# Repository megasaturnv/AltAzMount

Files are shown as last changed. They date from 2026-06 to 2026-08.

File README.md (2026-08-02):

> [!WARNING]
> This project is currently work in progress. Not everything will work as intended

# AltAzMount
Alt Az (Pan Tilt) mount that tracks celestial objects based on Right Ascension and Declination. It can accept LX200 commands from planetarium software such as Stellarium via serial or it calculate the position of certain objects directly on the ESP32 and track them across the sky (currently only the sun and moon)

video of Alt Az Mount design 2

## ESP32 Code
Contains the code for running on the ESP32 controller. it uses an MKS DLC32 as the main control board and has an OLED with rotary encoder as an interface.

## Python Code
Scripts that can control the mount to create an image based on the data received or simulate visualisations of Alt-Az movement.

## 3D Print Design 1 - Original Design (Old)

This design is now deprecated and it is recommended to use design 2 in this repository. The worm gears gave good precision but the large size introduced a lot of flex in the design

M3 screws and nut of various sizes required to build this mount. 4x M4 screws and nuts required for VESA mount.

## 3D Print Design 2 - Remix of isaac879
### This is remixed from isaac879's design here:
<https://github.com/isaac879/Pan-Tilt-Mount>  
<https://www.thingiverse.com/thing:4547074>  

### List of changes:
* Added 18650s
* Added OLED + rotary encoder board, 18650 USB C charge controller, balance board and battery gauge
* Added quick mount for tripods (varies slightly per tripod)
* Added stepper motor sun shields
* Added RTC module mount
* Added 40mm fan mount
* Added limit switch for altitude (tilt) axis
* Added more mounting options such as quick connect for a tripod and a ground spike
* Extended altitude (tilt) axis by 25mm upwards
* Modified camera mount to use VESA with 75mm spacing
* Modified design to use MKS DLC32 circuit board
* Square M3 nuts modified to take M3 hex nuts

M3 screws and nut of various sizes required to build this mount. 4x M4 screws and nuts required for VESA mount.

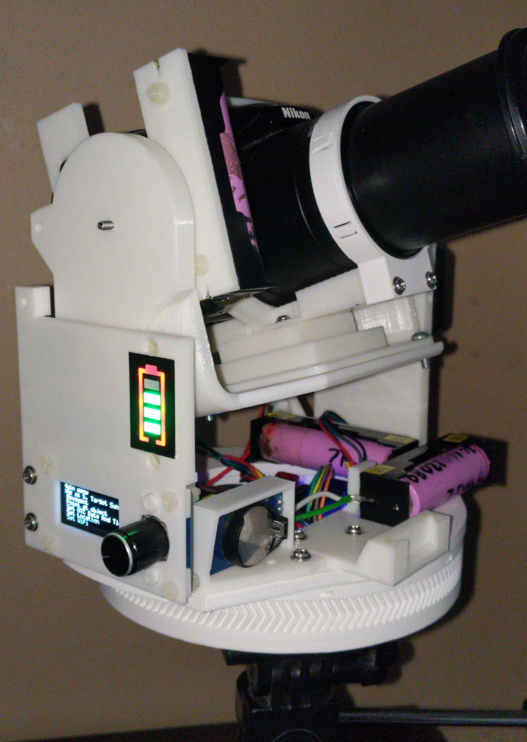
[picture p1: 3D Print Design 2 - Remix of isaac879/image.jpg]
image of Alt Az Mount design 2


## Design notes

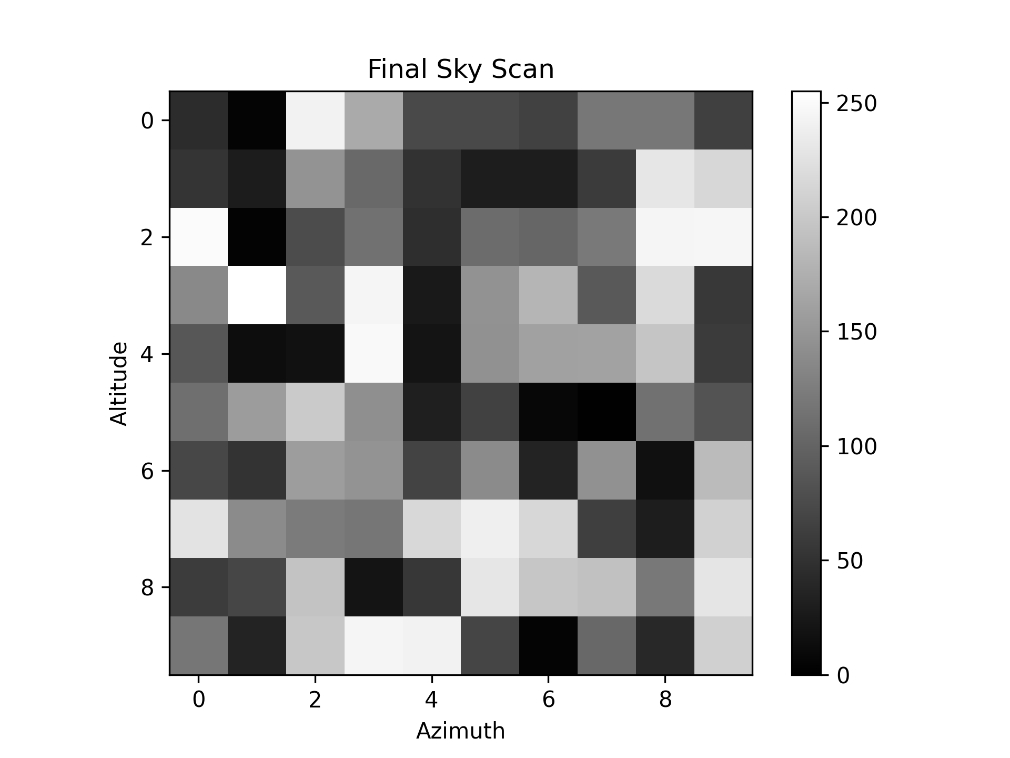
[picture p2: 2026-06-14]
Python Code/Scanning - Light Sensor/scan_2026-05-21_00-07-52 Random Data.png

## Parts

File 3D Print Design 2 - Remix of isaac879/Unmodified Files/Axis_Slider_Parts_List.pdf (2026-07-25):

isaac879

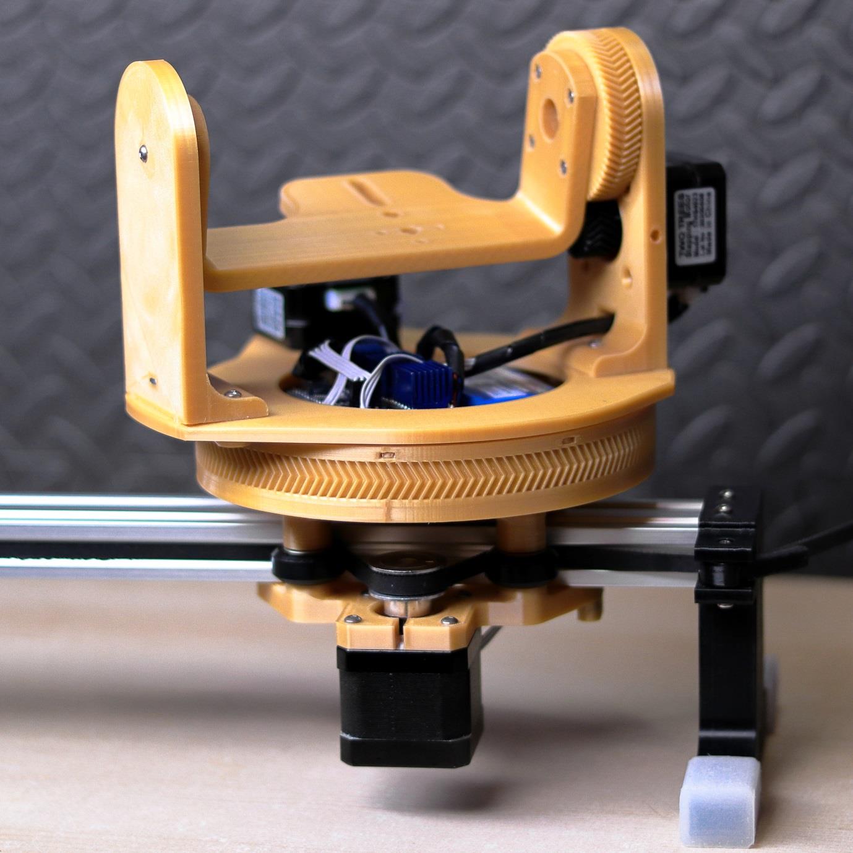
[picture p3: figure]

Linear Slider | Page 1 of 3

# 3-Axis Slider Parts List

3-Axis Slider Parts | Quantity
Nema 17 42 x 42 x 40mm Stepper Motor | 2
Nema 17 42 x 42 x 23mm Stepper Motor | 1
TMC2208 Stepper Motor Driver | 3
Arduino Nano | 1
JDY-31 Bluetooth Module (Alternatively HC-05, HC-06 or JDY-30) | 1
A3144 Hall Effect Sensor | 3
6.4mm diameter x 1.7mm Neodymium Magnets | 2
3.2mm diameter x 1.7mm Neodymium Magnets | 4
2N3904 NPN Transistor | 1
330Ω Resistor | 1
470Ω Resistor | 1
15kΩ Resistor | 1
22kΩ Resistor | 1
33kΩ Resistor | 2
100µF Electrolytic Capacitor | 3
2 Pin Plug-In Screw Terminal Block Connector 5.08mm Pitch (for power) | 1
6 Pin Female Header Connector 2.54mm (for Bluetooth module) | 1
15 Pin Female Header Connector 2.54mm (for Arduino Nano) | 2
15 Pin Male Header Connector 2.54mm (for Arduino Nano) | 2
8 Pin Female Header Connector 2.54mm (for Stepper drivers) | 6
8 Pin Male Header Connector 2.54mm (for Stepper drivers) | 6
XH2.54 4 Pin Terminal Socket Header (for Stepper motors) | 3
XH2.54 4 Pin Terminal Socket Plug (for Stepper motors) | 3
XH2.54 3 Pin Terminal Socket Header (for Hall Effect) | 3
XH2.54 3 Pin Terminal Socket Plug (for Hall Effect) | 3
XH2.54 2 Pin Terminal Socket Header (for camera shutter trigger) | 1
XH2.54 2 Pin Terminal Socket Plug (for camera shutter trigger) | 1
2.5mm 3 pole Jack Male (for camera trigger) | 1
11.1V 3S LiPo Battery or 12V DC Power Source and connector to screw terminal | 1
Pan Tilt Mount PCB | 1
Solder Wire
Cyanoacrylate or Hot Glue (for magnets and Hall Effect sensor) Wire (for Stepper motors, Hall sensors, Bluetooth module)
M3 Hexagonal Nyloc Nut | 16
M3 Square Nut | 10
M3 Button Head Hex Bolt 40mm | 4
M3 Button Head Hex Bolt 20mm | 3
M3 Button Head Hex Bolt 16mm | 10
M3 Button Head Hex Bolt 12mm | 14
M3 Button Head Hex Bolt 8mm | 5
M3 Button Head Hex Bolt 6mm | 5
M3 Button Head Hex Bolt 3.5mm | 1
Camera Mounting Bolt | 1
M3 T-Nut for Aluminium Extrusion Profile | 4

Screw 2mm Outer Thread Diameter, 6mm Long | 3
2GT Timing Belt | 1
2GT Timing Pulley 36 Teeth | 1
V-Slot 2040 Aluminium Extrusion | 1
F623ZZ Flange Bushing Ball Bearings 3 x 10 x 4mm | 6
V-Slot Pulley Wheels with Bearings (24 x 16 x 10.2mm) | 4
3D Printed Parts
127 x 146.05 x 12.7mm INA CSXU050-2RS Bearing Or 3D printable bearing parts 1-3 and 28 x 6mm balls (BB pellets) | 1
21 Tooth Herringbone Gear | 1
64 Tooth Herringbone Gear | 1
17 Tooth Herringbone Gear | 1
144 Tooth Herringbone Gear Base Mount | 1
Tilt U-Mount | 1
Idle Side Bearing Mount | 1
Gear Side Bearing Mount | 1
Idle Side Support | 1
Gear Side Support | 1
Pan Mount | 1
Pan Mount Bearing Clamp | 1
Base Mount Bearing Clip Ring | 1
2040 hall clamp | 1
2040 slider carriage top | 1
2040 slider carriage bottom | 1
2040 belt clamp side 1 | 1
2040 belt clamp side 2 | 1
2040 support leg (Optional)
Belt clamp lever | 2
3mm to 5mm wheel bearing spacer centred | 4
5mm to 8mm shaft spacer (for timing pulley if it has a 8mm bore) | 1

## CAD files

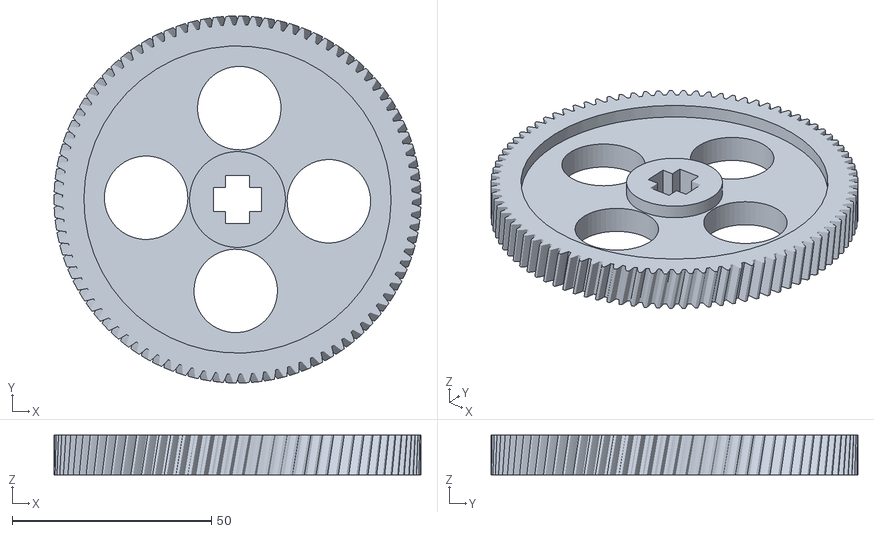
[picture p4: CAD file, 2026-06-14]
3D Prints - OpenSCAD/STLs/Main_WormGearDesign Nema 17_spur.stl
92.0 x 92.0 x 10.0

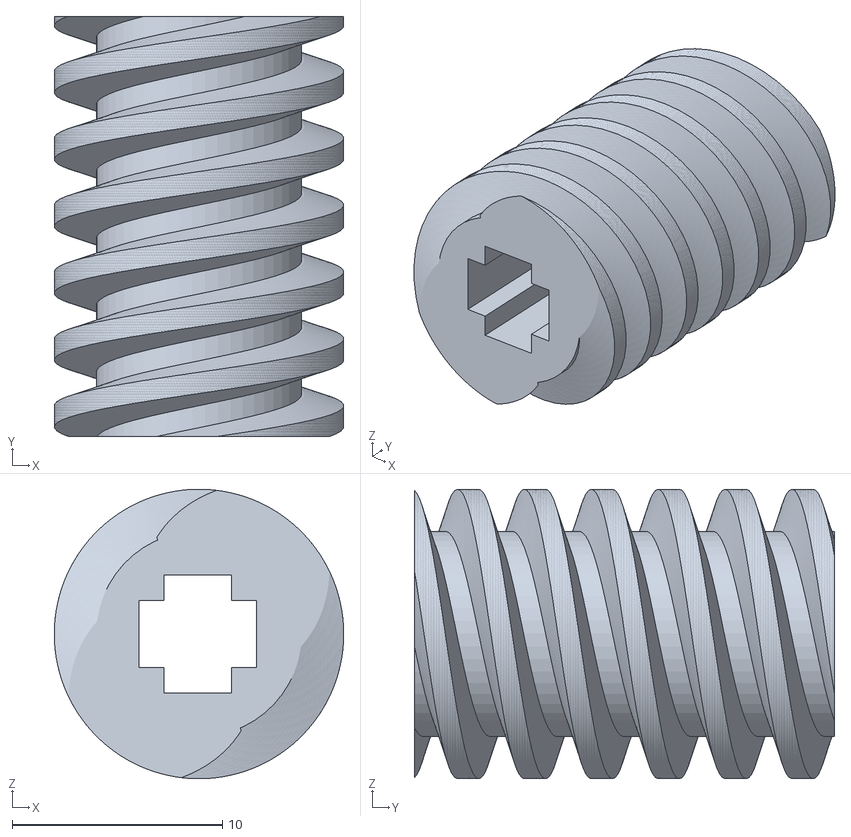
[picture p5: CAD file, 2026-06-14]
3D Prints - OpenSCAD/STLs/Main_WormGearDesign Nema 17_spur_worm_keyed.stl
13.8 x 20.0 x 13.8

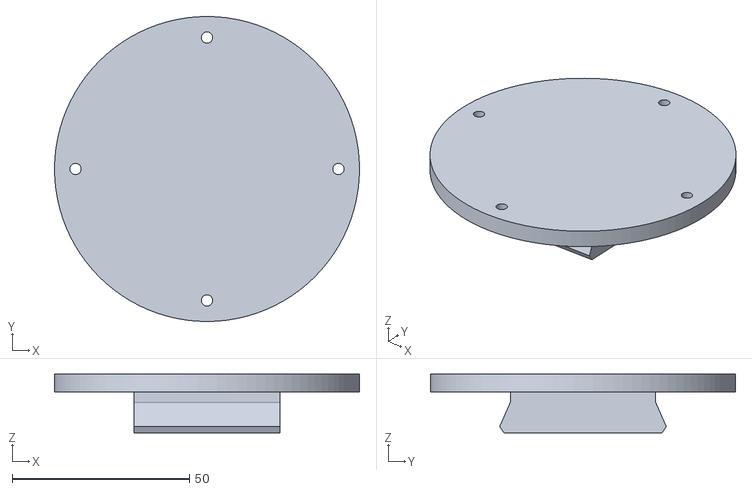
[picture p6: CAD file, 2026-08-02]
3D Print Design 2 - Remix of isaac879/New and Modified Files/Remix of isaac879 Pan Tilt Camera Mount_Tripod Mount.stl
86.0 x 86.0 x 16.6

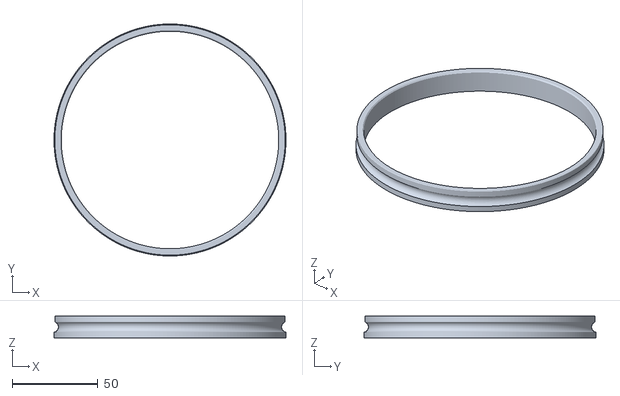
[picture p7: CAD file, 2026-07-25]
3D Print Design 2 - Remix of isaac879/Unmodified Files/127_x_146.05_x_12.7mm_Printable_Bearing_Part_2.stl
135.5 x 135.5 x 12.7

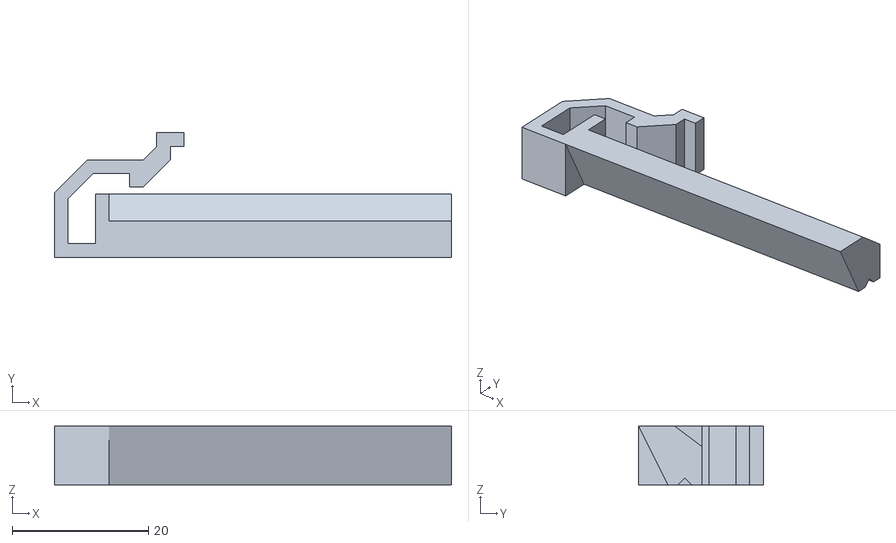
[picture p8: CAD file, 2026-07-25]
3D Prints - SketchUp/AltAzTrackerSketchup STLs/AltAzTrackerSketchup_Y Camera Mount Top Tripod Pin.stl
58.2 x 18.3 x 8.60

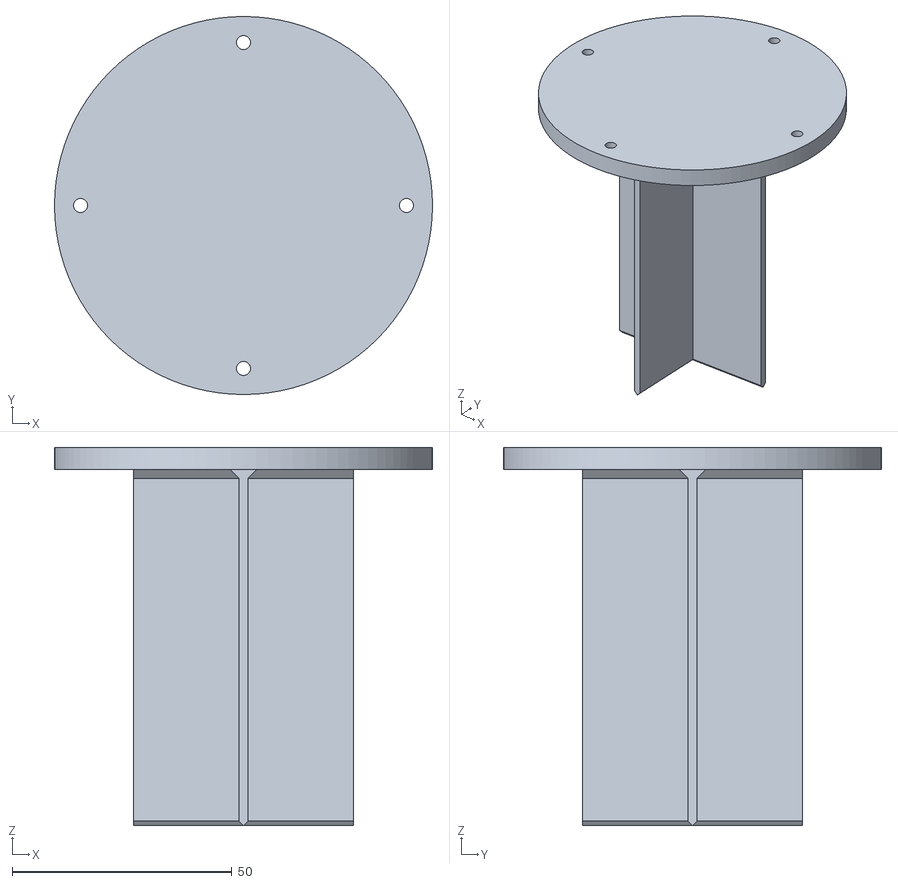
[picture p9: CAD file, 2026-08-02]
3D Print Design 2 - Remix of isaac879/New and Modified Files/Remix of isaac879 Pan Tilt Camera Mount_Ground Spike.stl
86.0 x 86.0 x 86.0

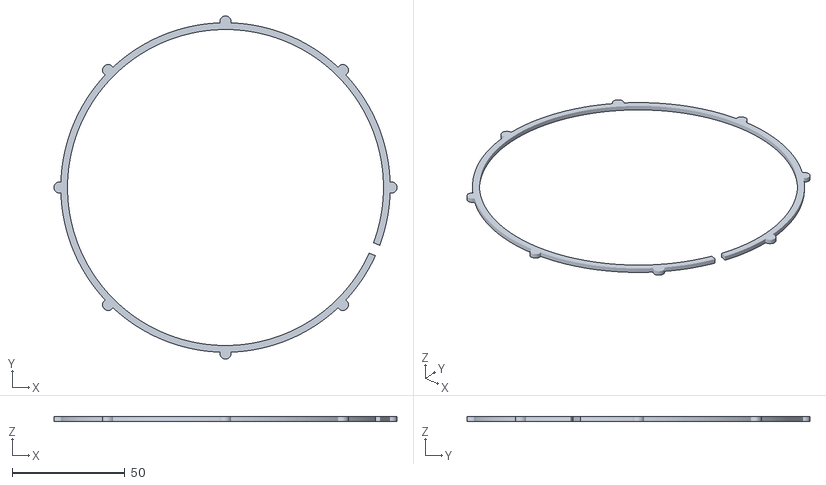
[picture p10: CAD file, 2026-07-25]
3D Print Design 2 - Remix of isaac879/Unmodified Files/Base_Mount_Bearing_Clip_Ring.stl
152.0 x 152.0 x 2.00

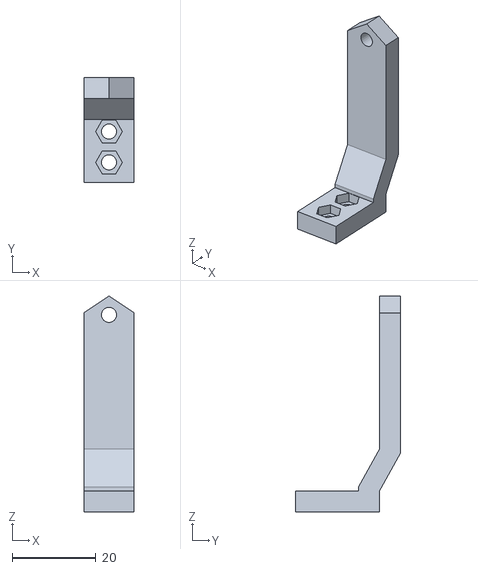
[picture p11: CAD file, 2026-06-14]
3D Prints - SketchUp/AltAzTrackerSketchup STLs/AltAzTrackerSketchup_Y axis holder support column.stl
12.0 x 25.0 x 51.5

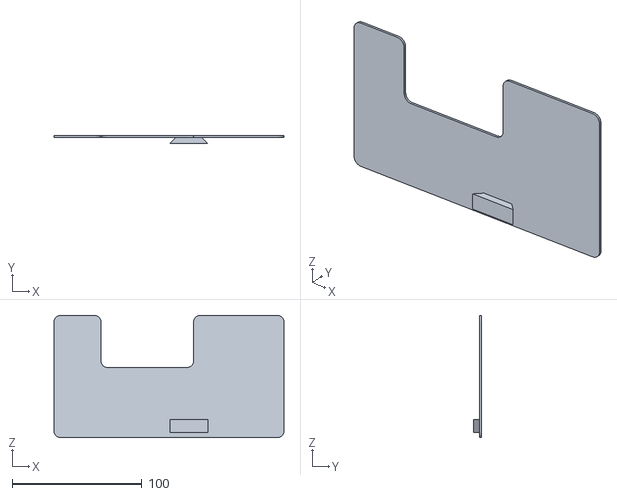
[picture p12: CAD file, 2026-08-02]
3D Print Design 2 - Remix of isaac879/New and Modified Files/Remix of isaac879 Pan Tilt Camera Mount_Pan Tilt Sun Shield.stl
177.0 x 6.00 x 94.0

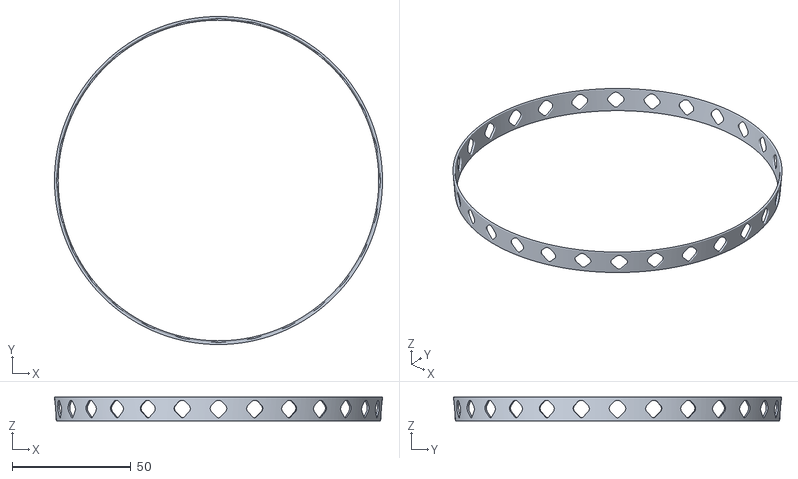
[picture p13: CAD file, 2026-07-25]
3D Print Design 2 - Remix of isaac879/Unmodified Files/127_x_146.05_x_12.7mm_Printable_Bearing_Cage_Part_3.stl
138.1 x 138.1 x 9.90

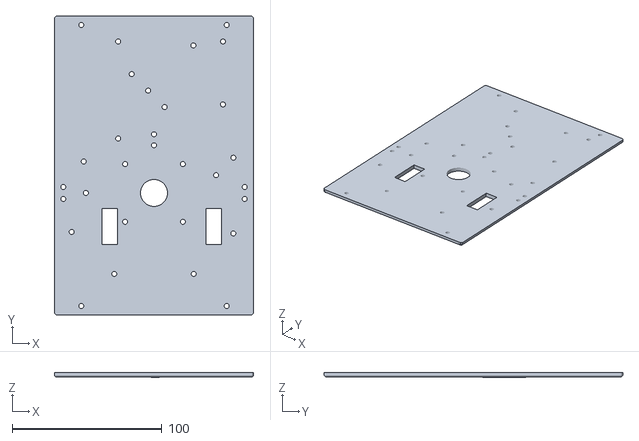
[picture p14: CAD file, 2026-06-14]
3D Prints - SketchUp/AltAzTrackerSketchup STLs/AltAzTrackerSketchup_X axis base.stl
133.0 x 199.4 x 3.01

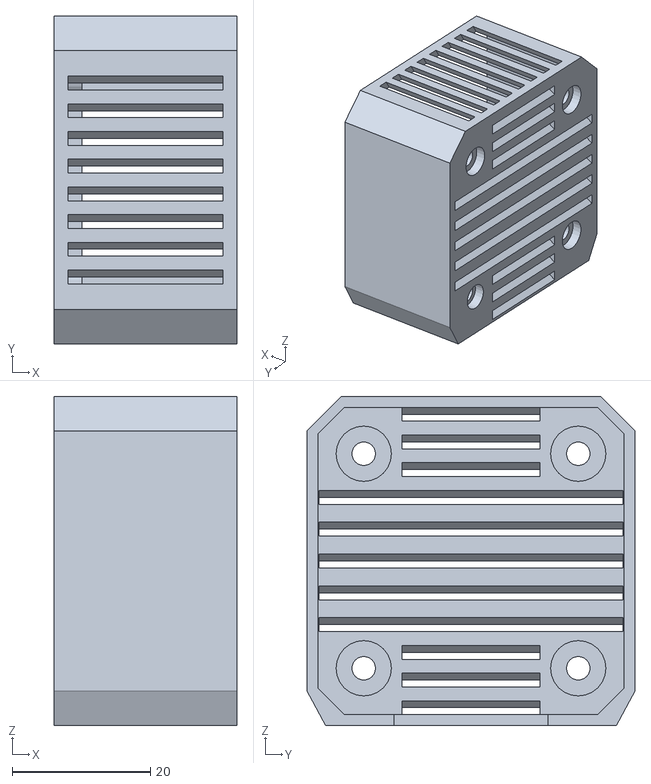
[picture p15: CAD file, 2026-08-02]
3D Print Design 2 - Remix of isaac879/New and Modified Files/Remix of isaac879 Pan Tilt Camera Mount_Stepper Motor Cover.stl
26.4 x 47.4 x 47.6

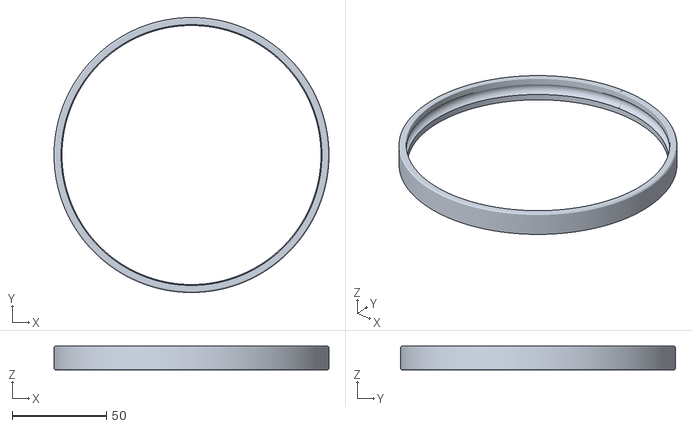
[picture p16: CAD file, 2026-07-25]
3D Print Design 2 - Remix of isaac879/Unmodified Files/127_x_146.05_x_12.7mm_Printable_Bearing_Part_1.stl
146.0 x 146.0 x 12.7

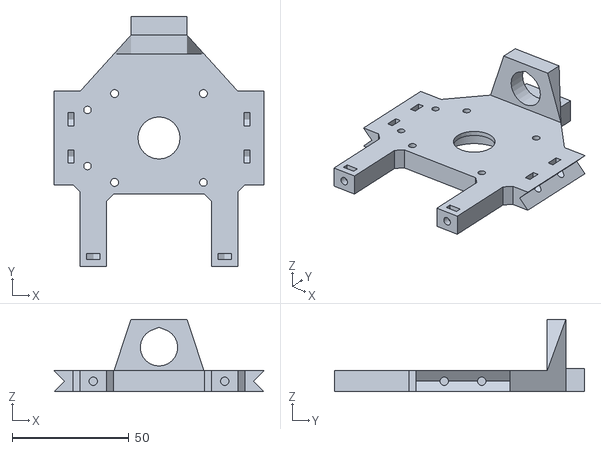
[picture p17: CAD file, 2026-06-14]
3D Prints - SketchUp/AltAzTrackerSketchup STLs/AltAzTrackerSketchup_Y axis holder 2.stl
89.8 x 107.0 x 31.0

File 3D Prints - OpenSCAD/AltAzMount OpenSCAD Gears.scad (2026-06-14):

// AltAzMount by MegaSaturnv

/////////////////////////////
// Customizable Parameters //
/////////////////////////////
/* [Basic] */
AZ_GEAR_DIAMETER = 90;
ALT_GEAR_DIAMETER = 90;

GEAR_KEY_TOOTH_WIDTH = 6;
GEAR_KEY_TOOTH_LENGTH = 3;
GEAR_KEY_DEPTH = 10;

WORM_KEY_TOOTH_WIDTH = 3.2;
WORM_KEY_TOOTH_LENGTH = 1.2;
WORM_KEY_DEPTH = 22;

STEPPER_SHAFT_KEY_DEPTH = 1.6;
STEPPER_SHAFT_KEY_LENGTH = 10;

SHOW_SPUR = true;
SHOW_WORM_KEYED = true;
SHOW_WORM_X_AXIS = false; //Not currently used
SHOW_WORM_Y_AXIS = false; //Not currently used

SPLIT_WORM = false; //Optional. May help some with printing



/* [Advanced] */
//Use $fn = 24 if it's a preview. $fn = 96 for the render. Increase 96 to produce a smoother curve.
$fn = $preview ? 24 : 96;

//////////////
// Includes //
//////////////
use <gears.scad>



/////////////
// Modules //
/////////////
module gear_key(ArgGearKeyToothWidth=GEAR_KEY_TOOTH_WIDTH, ArgGearToothLength=GEAR_KEY_TOOTH_LENGTH, ArgGearKeyDepth=GEAR_KEY_DEPTH) {
	union() {
		translate([-ArgGearToothLength - ArgGearKeyToothWidth/2, -ArgGearKeyToothWidth/2, 0]) cube([2*ArgGearToothLength + ArgGearKeyToothWidth, ArgGearKeyToothWidth, ArgGearKeyDepth + 0.02]);
		translate([-ArgGearKeyToothWidth/2, -ArgGearToothLength - ArgGearKeyToothWidth/2, 0]) cube([ArgGearKeyToothWidth, 2*ArgGearToothLength + ArgGearKeyToothWidth, ArgGearKeyDepth + 0.02]);
	}
}

module worm_key(ArgGearKeyToothWidth=WORM_KEY_TOOTH_WIDTH, ArgGearToothLength=WORM_KEY_TOOTH_LENGTH, ArgGearKeyDepth=WORM_KEY_DEPTH) {
	union() {
		translate([-ArgGearToothLength - ArgGearKeyToothWidth/2, -ArgGearKeyToothWidth/2, 0]) cube([2*ArgGearToothLength + ArgGearKeyToothWidth, ArgGearKeyToothWidth, ArgGearKeyDepth + 0.02]);
		translate([-ArgGearKeyToothWidth/2, -ArgGearToothLength - ArgGearKeyToothWidth/2, 0]) cube([ArgGearKeyToothWidth, 2*ArgGearToothLength + ArgGearKeyToothWidth, ArgGearKeyDepth + 0.02]);
	}
}

module Main_Gears_Worm_x_axis() {
	worm_gear(modul=1, tooth_number=AZ_GEAR_DIAMETER, thread_starts=2, width=10, length=20, worm_bore=0, gear_bore=4, pressure_angle=20, lead_angle=9.5, optimized=true, together_built=true, show_spur=false, show_worm=true);

	translate([6, 23.5 + 11.15, 0]) difference() {
		rotate([90, 0, 0]) cylinder(d=6.4, h=23.5 + 1);
		translate([-6.4/2, -STEPPER_SHAFT_KEY_LENGTH, 6.4/2 - STEPPER_SHAFT_KEY_DEPTH]) cube([6.4, STEPPER_SHAFT_KEY_LENGTH, 6.4]);
	}

	translate([6, -8.8, 0]) rotate([90, 0, 0]) cylinder(d=10, h=13);
	translate([6, -8.8 + 1, 0]) rotate([90, 0, 0]) cylinder(d=8, h=13 + 8 + 1);
}

module Main_Gears_Worm_y_axis() {
	worm_gear(modul=1, tooth_number=ALT_GEAR_DIAMETER, thread_starts=2, width=10, length=20, worm_bore=0, gear_bore=4, pressure_angle=20, lead_angle=9.5, optimized=true, together_built=true, show_spur=false, show_worm=true);

	translate([6, 26 + 11.15, 0]) difference() {
		rotate([90, 0, 0]) cylinder(d=6.4, h=26 + 1);
		translate([-6.4/2, -STEPPER_SHAFT_KEY_LENGTH, 6.4/2 - STEPPER_SHAFT_KEY_DEPTH]) cube([6.4, STEPPER_SHAFT_KEY_LENGTH, 6.4]);
	}

	translate([6, -8.8, 0]) rotate([90, 0, 0]) cylinder(d=10, h=26);
	translate([6, -8.8 + 1, 0]) rotate([90, 0, 0]) cylinder(d=8, h=26 + 8 + 1);
}

module Main_Gears_Worm_keyed() {
	difference() {
		worm_gear(modul=1, tooth_number=ALT_GEAR_DIAMETER, thread_starts=2, width=10, length=20, worm_bore=0, gear_bore=4, pressure_angle=20, lead_angle=9.5, optimized=true, together_built=true, show_spur=false, show_worm=true);
		translate([6, -8.8 + 21, 0]) rotate([90, 0, 0]) worm_key();
	}
}


////////////////
// Main Model //
////////////////
//Spur
if (SHOW_SPUR) {
	difference() {
		union() {
			worm_gear(modul=1, tooth_number=AZ_GEAR_DIAMETER, thread_starts=2, width=10, length=20, worm_bore=4, gear_bore=4, pressure_angle=20, lead_angle=10, optimized=true, together_built=true, show_spur=true, show_worm=false);
			translate([-AZ_GEAR_DIAMETER/2, 0, -GEAR_KEY_DEPTH/2]) cylinder(d=24, h=GEAR_KEY_DEPTH);
		}
		translate([-AZ_GEAR_DIAMETER/2, 0, -5.01]) gear_key();
	}
}

//Worm X axis
if (SHOW_WORM_X_AXIS) {
	if (SPLIT_WORM) {
		//Half 1
		translate([-15, 0, 0]) difference() {
			Main_Gears_Worm_x_axis();
			translate([-200, -200, -100]) cube([400,400,100]);
		}
		//Half 2
		translate([15, 0, 0]) difference() {
			rotate([0, 180, 0]) Main_Gears_Worm_x_axis();
			translate([-200, -200, -100]) cube([400,400,100]);
		}

	} else {
		rotate([0, 0, 0]) Main_Gears_Worm_x_axis();
	}
}

//Worm Y axis
if (SHOW_WORM_Y_AXIS) {
	if (SPLIT_WORM) {
		//Half 1
		translate([-15, 0, 0]) difference() {
			Main_Gears_Worm_y_axis();
			translate([-200, -200, -100]) cube([400,400,100]);
		}
		//Half 2
		translate([15, 0, 0]) difference() {
			rotate([0, 180, 0]) Main_Gears_Worm_y_axis();
			translate([-200, -200, -100]) cube([400,400,100]);
		}

	} else {
		rotate([0, 0, 0]) Main_Gears_Worm_y_axis();
	}
}

//Worm keyed version
if (SHOW_WORM_KEYED) {
	if (SPLIT_WORM) {
		//Half 1
		translate([-15, 0, 0]) difference() {
			Main_Gears_Worm_keyed();
			translate([-200, -200, -100]) cube([400,400,100]);
		}
		//Half 2
		translate([15, 0, 0]) difference() {
			rotate([0, 180, 0]) Main_Gears_Worm_keyed();
			translate([-200, -200, -100]) cube([400,400,100]);
		}

	} else {
		rotate([0, 0, 0]) Main_Gears_Worm_keyed();
	}
}

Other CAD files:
3D Print Design 2 - Remix of isaac879/New and Modified Files/Remix of isaac879 Pan Tilt Camera Mount_Camera Mount Top Tripod Pin.stl
3D Print Design 2 - Remix of isaac879/Unmodified Files/Hall_Effect_Stepper_Mount.stl
3D Prints - SketchUp/AltAzTrackerSketchup STLs/AltAzTrackerSketchup_Y Worm Gear Shaft 2.stl
3D Print Design 2 - Remix of isaac879/New and Modified Files/Remix of isaac879 Pan Tilt Camera Mount_Camera Mount Top Tripod.stl
3D Print Design 1 - Original Design (Old)/3D Prints - SketchUp/AltAzTrackerSketchup STLs/AltAzTrackerSketchup_18650 Sideways Battery Holder.stl
3D Print Design 1 - Original Design (Old)/3D Prints - SketchUp/AltAzTrackerSketchup STLs/AltAzTrackerSketchup_Base Vertical Shaft 1.stl
3D Print Design 1 - Original Design (Old)/3D Prints - SketchUp/AltAzTrackerSketchup STLs/AltAzTrackerSketchup_Base Vertical Shaft 2.stl
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

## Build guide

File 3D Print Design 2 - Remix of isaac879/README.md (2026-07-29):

#     3D Print Design 2 - Remix of isaac879
This is remixed from isaac879's design here:  
<https://github.com/isaac879/Pan-Tilt-Mount>  
<https://www.thingiverse.com/thing:4547074>  

Google SketchUp version 8.0.14346 was used to modify the original design

### List of changes:
* Added 18650s
* Added OLED + rotary encoder board, 18650 USB C charge controller, balance board and battery guage
* Added quick mount for tripods (varies slightly per tripod)
* Added stepper motor sun shields
* Added RTC module mount
* Added 40mm fan mount
* Added limit switch for altitude (tilt) axis
* Extended altitude (tilt) axis by 25mm upwards
* Modified camera mount to use VESA with 75mm spacing
* Modified design to use MKS DLC32 circuit board
* Square M3 nuts modified to take M3 hex nuts

M3 screws and nut of various sizes required to build this mount. 4x M4 screws and nuts required for VESA mount.

video of Alt Az Mount design 2

image of Alt Az Mount design 2

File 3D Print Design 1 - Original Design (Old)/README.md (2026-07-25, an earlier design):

#     3D Print Design 1 - Original Design (Old)

This design is now deprecated and it is recommended to use design 2 in this repository. The worm gears gave good precision but the large size introduced a lot of flex in the design

M3 screws and nut of various sizes required to build this mount. 4x M4 screws and nuts required for VESA mount.

### 3D prints - SketchUp
Contains the main model for 3d printing. Uses SketchUp version 8.0.14346

### 3D prints - OpenSCAD
Contains the worm gear and spur gear for the mechanism. Uses gears.scad from https://github.com/chrisspen/gears

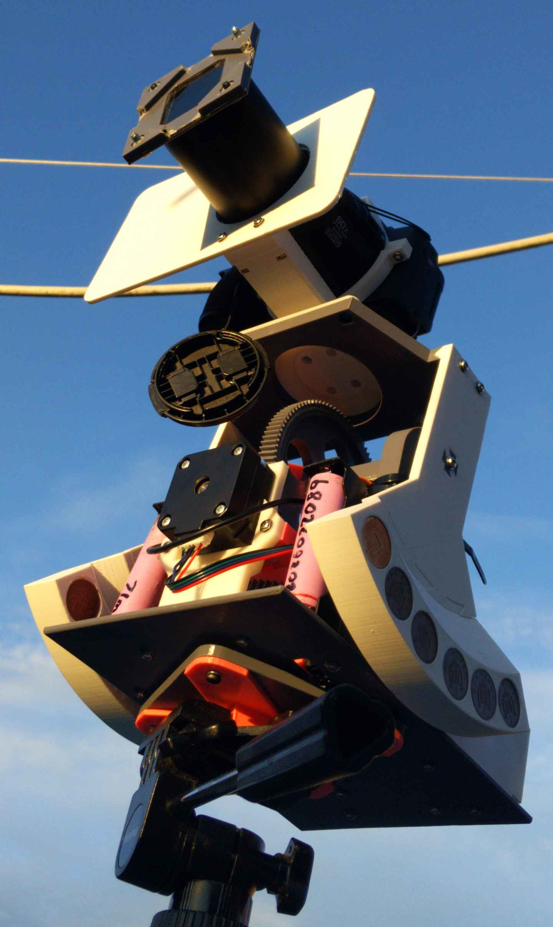
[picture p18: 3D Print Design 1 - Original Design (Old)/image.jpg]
image of Alt Az Mount design 1


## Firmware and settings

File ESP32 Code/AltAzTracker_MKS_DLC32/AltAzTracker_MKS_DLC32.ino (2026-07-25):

// ###################################
// ### MKS DLC32 v2.1 AltAzTracker ###
// ###################################

// ###################
// # Define settings #
// ###################
#include "settings.h"



// ############
// # Includes #
// ############
#include <Arduino.h>
#include <WiFi.h>
#include <ArduinoOTA.h>
#include <esp_bt.h>


//#include <stdint.h>
//#include <stdlib.h>
//#include <absstring.h>
//#include <math.h>

// I2C OLED Devices
#include <Wire.h>

#if DISPLAY_OUTPUT == SSD1306
  #include <SSD1306Ascii.h>
  #include <SSD1306AsciiWire.h>
#elif DISPLAY_OUTPUT == SH1106
  #include <U8g2lib.h>
#endif

#include <menu.h>
#include <menuIO/keyIn.h>
#include <menuIO/chainStream.h>
#if DISPLAY_OUTPUT == SSD1306
  #include <menuIO/SSD1306AsciiOut.h>
#elif DISPLAY_OUTPUT == SH1106
  #include <menuIO/u8g2Out.h>
#endif

#include <ClickEncoder.h> // Using this library: https://github.com/soligen2010/encoder
#include <menuIO/clickEncoderIn.h>

using namespace Menu; //Copied from example code. Alternative is to use Menu::x

#if DISPLAY_OUTPUT == SSD1306
  // #define menuFont System5x7
  #define menuFont lcd5x7
  #define fontW 5
  #define fontH 8
#elif DISPLAY_OUTPUT == SH1106
  #define menuFont u8g2_font_7x13_mf
  //#define menuFont u8g2_font_6x12_tf
  #define fontW 7
  #define fontH 16
  #define offsetX 0
  #define offsetY 3
  #define U8_Width 128
  #define U8_Height 64
  #define USE_HWI2C
#endif



// ##############
// # Structures #
// ##############
#include "structures.h"



// ##################
// # Const settings #
// ##################
#include "settings.h"



// ####################
// # Global Variables #
// ####################
#include "global_variables.h"



// ############################################################
// # custom class_AltAzPreferences.h which uses preferences.h #
// ############################################################
#include "class_AltAzPreferences.h"



// ##################################
// # Functions for AltAzPreferences #
// ##################################
#include "functions_AltAzPreferences.h"



// ################
// # Menu Defines #
// ################
#include "arduino_menu.h"



// ################################
// # Functions for Shift Register #
// ################################
#include "functions_shift_register.h"



// ##########################################
// # Custom AccelStepper Library Overwrites #
// ##########################################
#include "custom_AccelStepper_overwrites.h"



// ######################################
// # Alt/Az RA/Dec conversion functions #
// ######################################
#include "functions_AltAz_RADec_conversion.h"



// #######################
// # OLED print function #
// #######################
#include "functions_oled_print.h"



// ##########################
// # Functions for movement #
// ##########################
#include "functions_movement.h"



// #######################################
// # Functions for LX200 Serial Commands #
// #######################################
#include "functions_LX200.h"



// #############################################################################
// # Functions for calculating the RA and Dec of objects like the sun and moon # 
// #############################################################################
#include "functions_Calculate_RA_Dec_Of_Object.h"



// ##################
// # Menu Structure #
// ##################
char alphaNumericCharacters[] MEMMODE = " abcdefghijklmnopqrstuvwxyzABCDEFGHIJKLMNOPQRSTUVWXYZ0123456789";
char* constMEM alphaNumericCharactersValidator[] MEMMODE = {
  alphaNumericCharacters, alphaNumericCharacters, alphaNumericCharacters, alphaNumericCharacters, alphaNumericCharacters,
  alphaNumericCharacters, alphaNumericCharacters, alphaNumericCharacters, alphaNumericCharacters, alphaNumericCharacters,
  alphaNumericCharacters, alphaNumericCharacters, alphaNumericCharacters, alphaNumericCharacters, alphaNumericCharacters,
  alphaNumericCharacters, alphaNumericCharacters, alphaNumericCharacters, alphaNumericCharacters, alphaNumericCharacters
};

//#include "arduino_menu_structure.h"
// https://github.com/neu-rah/ArduinoMenu/wiki/Menu-definition
//FIELD Parameters: var.name, title, units, min., max., step size, fine step size, action, events mask, styles

// define menu colors --------------------------------------------------------
//each color is in the format:
//  { {disabled normal,disabled selected}, {enabled normal,enabled selected, enabled editing} }
// this is a monochromatic color table
const colorDef<uint8_t> colors[6] MEMMODE={
  {{0,0},{0,1,1}},//bgColor
  {{1,1},{1,0,0}},//fgColor
  {{1,1},{1,0,0}},//valColor
  {{1,1},{1,0,0}},//unitColor
  {{0,1},{0,0,1}},//cursorColor
  {{1,1},{1,0,0}},//titleColor
};

const char* const celestialObjects[] = {
    "Sun",
    "Moon",
//    "Mercury",
//    "Venus",
//    "Mars",
//    "Jupiter",
//    "Saturn",
//    "Uranus",
//    "Neptune"
};

//const int objectCount = sizeof(celestialObjects) / sizeof(celestialObjects[0]);
int selectedObject = 0;

int azPosHomeAs = 180;

// # Menu events
//Return options can be proceed and quit but documentation is sparse
//You can also return button inputs like "nav.doNav(escCmd)"
// when menu is suspended
result idle(menuOut &o, idleEvent e) {
  o.clear();

  switch (e) {//FIELD Parameters: var.name, title, units, min., max., step size, fine step size, action, events mask, styles
    case idleStart:
      o.println("suspending menu!");
      //steppersEnable(false);
      break;
    case idling:
      //o.println("suspended...");
      o.printf("%d %d %d %d %d %d\n", rtcESP32Time.getYear(),    rtcESP32Time.getMonth()+1,    rtcESP32Time.getDay(),    rtcESP32Time.getHour(true),   rtcESP32Time.getMinute(),    rtcESP32Time.getSecond()    );
      o.printf("%f, %f\n", latitudeDecimal, longitudeDecimal);
      break;
    case idleEnd:
      o.println("resuming menu.");
      break;
  }

  return proceed;
}

result op_AzSouthPointAtSun(eventMask e) {
  //Alt - Stop and home alt
  stepperAlt.stop();
  hasHomePositionAlt = performAltHome();

  //Az - Stop stepper and set current position to 180 (south)
  stepperAz.stop();
  azStepperMotorSetCurrentPositionToAngle(azPosHomeAs);

  setTargetToObject(celestialObjects[0]);
  trackingRADecTarget = true;
  return proceed;
}

result menuEvent_updateNewDateAndTimeVariable(eventMask e) {
  setNewDateAndTime.tm_year = rtcESP32Time.getYear();
  setNewDateAndTime.tm_mon = rtcESP32Time.getMonth();
  setNewDateAndTime.tm_mday = rtcESP32Time.getDay();
  setNewDateAndTime.tm_hour = rtcESP32Time.getHour(true);
  setNewDateAndTime.tm_min = rtcESP32Time.getMinute();
  setNewDateAndTime.tm_sec = rtcESP32Time.getSecond();
  return proceed;
}

result menuEvent_updateLatitudeDecimal(eventMask e) {
  latitudeDecimal = dmsToDegrees(latitudeDMSDegrees, latitudeDMSMinutes, latitudeDMSSeconds);
  return proceed;
}

result menuEvent_updateLongitudeDecimal(eventMask e) {
  longitudeDecimal = dmsToDegrees(longitudeDMSDegrees, longitudeDMSMinutes, longitudeDMSSeconds);
  return proceed;
}

result op_setLatLong(eventMask e) {
  altAzPreferences.setLatitude(latitudeDecimal);
  altAzPreferences.setLongitude(longitudeDecimal);
  return quit;
}

result op_setWifi(eventMask e) {
  altAzPreferences.setWifiSsid(wifiSsid);
  altAzPreferences.setWifiPassword(wifiPassword);
  return quit;
}

result op_setDatetimeOnRTC(eventMask e) {
  rtcDS3231.adjust(DateTime(
    setNewDateAndTime.tm_year,
    setNewDateAndTime.tm_mon,
    setNewDateAndTime.tm_mday,
    setNewDateAndTime.tm_hour,
    setNewDateAndTime.tm_min,
    setNewDateAndTime.tm_sec
  ));
  rtcESP32Time.setTime(
    setNewDateAndTime.tm_sec,
    setNewDateAndTime.tm_min,
    setNewDateAndTime.tm_hour,
    setNewDateAndTime.tm_mday,
    setNewDateAndTime.tm_mon,
    setNewDateAndTime.tm_year
  );
  return quit;
}

result op_disableSteppers(eventMask e) {
  steppersEnable(false);
  return proceed;
}

result op_performAltHome(eventMask e) {
  hasHomePositionAlt = performAltHome();
  positionSetTargetAngleAltitude(0.0);
  return proceed;
}

result op_performAzHome(eventMask e) {
  hasHomePositionAz = performAzHome();
  return proceed;
}

result op_FactoryReset(eventMask e) {
  altAzPreferences.factoryReset();
  LoadPreferencesIntoMemory();
  return quit;
}

result menuEvent_azPosHomeAs(eventMask e) {
  char stringAzPosHomeAs[] = "   ";
  itoa(azPosHomeAs, stringAzPosHomeAs, 10);
  //sprintf(azPosHomeAs, "%d", stringAzPosHomeAs);
  OLED_print(stringAzPosHomeAs, INFO); //Char array is purely for printing to screen. Currently testing better options

  //Stop stepper and set current position to specified angle (0=N, 90=E, 180=S, 270=W)
  stepperAz.stop();
  azStepperMotorSetCurrentPositionToAngle(azPosHomeAs);

  return proceed;
}

result op_setTargetToObject(eventMask e) {
    setTargetToObject(celestialObjects[selectedObject]);
    return proceed;
}

result op_beginTracking(eventMask e) {
  trackingRADecTarget = true;
  return proceed;
}

result op_stopTracking(eventMask e) {
  trackingRADecTarget = false;
  return proceed;
}



// # Menu items
MENU(subMenu_SetDateAndTime, "Set UTC Date And Time", menuEvent_updateNewDateAndTimeVariable, enterEvent, noStyle
  , FIELD(setNewDateAndTime.tm_year,"Year","", 2000, 2100, 10, 1, doNothing, noEvent, noStyle)
  , FIELD(setNewDateAndTime.tm_mon,"Month","", 1, 12, 10, 1, doNothing, noEvent, noStyle) //todo, use intermediate month variable which is tm_mon + 1
  , FIELD(setNewDateAndTime.tm_mday,"Day","", 1, 31, 10, 1, doNothing, noEvent, noStyle)
  , FIELD(setNewDateAndTime.tm_hour,"Hour","", 0, 23, 10, 1, doNothing, noEvent, noStyle)
  , FIELD(setNewDateAndTime.tm_min,"Minute","", 0, 59, 10, 1, doNothing, noEvent, noStyle)
  , FIELD(setNewDateAndTime.tm_sec,"Second","", 0, 59, 10, 1, doNothing, noEvent, noStyle)
  , OP("Set datetime on RTC", op_setDatetimeOnRTC, enterEvent)
  , EXIT("<Back")
);

MENU(subMenu_SetLatitude, "Set Latitude", doNothing, noEvent, noStyle
  //, FIELD(latitudeDecimal,"Lat","°", -90.0, 90.0, 10, 0.1, menuEvent_updateLatitudeDMS, enterEvent, noStyle)
  , FIELD(latitudeDecimal,"Lat","°", -90.0, 90.0, 10, 0.1, doNothing, noEvent, noStyle)
  , FIELD(latitudeDMSDegrees, "Lat Deg", "°", -90, 90, 10, 1, menuEvent_updateLatitudeDecimal, enterEvent, noStyle)
  , FIELD(latitudeDMSMinutes, "Lat Min", "'", 0, 59, 10, 1, menuEvent_updateLatitudeDecimal, enterEvent, noStyle)
  , FIELD(latitudeDMSSeconds, "Lat Sec", "\"", 0, 59, 10, 0.1, menuEvent_updateLatitudeDecimal, enterEvent, noStyle)
  , EXIT("<Back")
);

MENU(subMenu_SetLongitude, "Set Longitude", doNothing, noEvent, noStyle
  //, FIELD(longitudeDecimal,"Long","°", -90.0, 90.0, 10, 0.1, menuEvent_updateLongitudeDMS, enterEvent, noStyle)
  , FIELD(longitudeDecimal,"Long","°", -90.0, 90.0, 10, 0.1, doNothing, noEvent, noStyle)
  , FIELD(longitudeDMSDegrees, "Long Deg", "°", -90, 90, 10, 1, menuEvent_updateLongitudeDecimal, enterEvent, noStyle)
  , FIELD(longitudeDMSMinutes, "Long Min", "'", 0, 59, 10, 1, menuEvent_updateLongitudeDecimal, enterEvent, noStyle)
  , FIELD(longitudeDMSSeconds, "Long Sec", "\"", 0, 59, 10, 0.1, menuEvent_updateLongitudeDecimal, enterEvent, noStyle)
  , EXIT("<Back")
);

MENU(subMenu_SetLocation, "Set Location", doNothing, noEvent, noStyle
  , SUBMENU(subMenu_SetLatitude)
  , SUBMENU(subMenu_SetLongitude)
  , OP("Save new LatLong", op_setLatLong, enterEvent)
  , EXIT("<Back")
);

MENU(subMenu_SetWifi, "Set WiFi", doNothing, noEvent, noStyle
  , EDIT("SSID", wifiSsid, alphaNumericCharactersValidator, doNothing, noEvent, noStyle)
  , EDIT("Pwd", wifiPassword, alphaNumericCharactersValidator, doNothing, noEvent, noStyle)
  , OP("Save new WiFi creds", op_setWifi, enterEvent)
  , EXIT("<Back")
);

CHOOSE(azPosHomeAs, choose_azPosHomeAs, "Set Az Home as", doNothing, noEvent, noStyle
  , VALUE("North here", 0, menuEvent_azPosHomeAs, enterEvent)
  , VALUE("East here", 90, menuEvent_azPosHomeAs, enterEvent)
  , VALUE("South here", 180, menuEvent_azPosHomeAs, enterEvent)
  , VALUE("West here", 270, menuEvent_azPosHomeAs, enterEvent)
);

MENU(subMenu_Movement, "Movement", doNothing, noEvent, noStyle
  , FIELD(angleOffsetAlt, "Alt Offset", "°", -45, 45, 1, 0.1, doNothing, noEvent, noStyle)
  , FIELD(angleOffsetAz, "Az Offset", "°", -45, 45, 1, 0.1, doNothing, noEvent, noStyle)
  , OP("Begin Tracking", op_beginTracking, enterEvent)
  , OP("Stop Tracking", op_stopTracking, enterEvent)
  , OP("Perform Alt Home", op_performAltHome, enterEvent)
  , OP("Perform Az Home", op_performAzHome, enterEvent)
  , SUBMENU(choose_azPosHomeAs)
  , OP("Disable Steppers", op_disableSteppers, enterEvent)
  , EXIT("<Back")
);

CHOOSE(selectedObject, subMenu_choose_PointAtObject, "Object:", doNothing, noEvent, noStyle
    , VALUE("Sun",      0, doNothing, noEvent)
    , VALUE("Moon",     1, doNothing, noEvent)
//    , VALUE("Mercury",  2, doNothing, noEvent)
//    , VALUE("Venus",    3, doNothing, noEvent)
//    , VALUE("Mars",     4, doNothing, noEvent)
//    , VALUE("Jupiter",  5, doNothing, noEvent)
//    , VALUE("Saturn",   6, doNothing, noEvent)
//    , VALUE("Uranus",   7, doNothing, noEvent)
//    , VALUE("Neptune",  8, doNothing, noEvent)
);

MENU(subMenu_PointAtObject, "Point at object", doNothing, noEvent, noStyle
  , SUBMENU(subMenu_choose_PointAtObject)
  , OP("Set target to object above", op_setTargetToObject, enterEvent)
  , OP("Begin Tracking target", op_beginTracking, enterEvent)
  , OP("Stop Tracking target ", op_stopTracking, enterEvent)
  , EXIT("<Back")
);

TOGGLE(tripodModeAltAz, toggle_tripodModeAltAz, "Tripod Mode: ", doNothing, noEvent, noStyle
  , VALUE("AltAz", true, doNothing, noEvent)
  , VALUE("RADec", false, doNothing, noEvent)
);

MENU(subMenu_FactoryReset, "Factory Reset", doNothing, noEvent, noStyle
  , OP("Are you sure?", doNothing, noEvent)
  , OP("Yes", op_FactoryReset, enterEvent)
  , EXIT("No")
  , EXIT("<Back")
);



MENU(mainMenu, "Main menu", doNothing, noEvent, noStyle
  , OP("Az as S. Target Sun", op_AzSouthPointAtSun, enterEvent)
  , SUBMENU(subMenu_Movement)
  , SUBMENU(subMenu_PointAtObject)
  , SUBMENU(subMenu_SetDateAndTime)
  , SUBMENU(subMenu_SetLocation)
  , SUBMENU(subMenu_SetWifi)
  , SUBMENU(toggle_tripodModeAltAz)
  , SUBMENU(subMenu_FactoryReset)
  , EXIT("<Back to Idle Screen")
);



// ##########################
// # Menu inputs and output #
// ##########################
//input section
// Declare the clickencoder
ClickEncoder clickEncoder = ClickEncoder(PIN_EXP2_TRA, PIN_EXP2_TRB, -1, ENCODER_SENSITIVITY); // -1 means don't pass through an input button here. That will be handled by joystickBtn_map later
ClickEncoderStream encStream(clickEncoder, 1); // Number means number of rotary steps to move menu, after sensitivity has been set properly. 1 step = move menu by 1

// Start the ESP32 timer to read the clickEncoder every 1 ms
//void IRAM_ATTR onTimer() { // ESP32 core 2.x
void ARDUINO_ISR_ATTR onTimer() { // ESP32 core 3.x
  clickEncoder.service();
}

// Build a map of keys to menu commands
// Negative pin numbers use internal pull-up, this is on when low
keyMap joystickBtn_map[] = {
  { (int8_t)(-1 * PIN_EXP2_CONFIRM), defaultNavCodes[enterCmd].ch} ,
  { (int8_t)(-1 * PIN_EXP1_BACK), defaultNavCodes[escCmd].ch}  ,
};
keyIn<TOTAL_NAV_BUTTONS> joystickBtns(joystickBtn_map); // The input driver

// Input from the encoder + joystick buttons
MENU_INPUTS(in, &encStream, &joystickBtns); //Macro shortcut

// Output section
// Define at least one panel for menu output
#if DISPLAY_OUTPUT == SSD1306
  //const panel panels[] MEMMODE = {  { &mainMenu, 0, 1, 128 / fontW, (64 / fontH)-1} }; //Start at row 1 to leave the top row available for messages. Total rows is therefore -1 to not go off-screen
  const panel panels[] MEMMODE = {  {0, 1, 128 / fontW, (64 / fontH)-1} }; //Start at row 1 to leave the top row available for messages. Total rows is therefore -1 to not go off-screen
#elif DISPLAY_OUTPUT == SH1106
  const panel panels[] MEMMODE = { {0, 1, 132 / fontW, (64 / fontH)-1} }; //Start at row 1 to leave the top row available for messages. Total rows is therefore -1 to not go off-screen
#endif

navNode* nodes[sizeof(panels) / sizeof(panel)]; // navNodes to store navigation status
panelsList pList(panels, nodes, 1); // A list of panels and nodes
idx_t tops[MAX_DEPTH] = {0, 0}; // Store cursor positions for each level

#if DISPLAY_OUTPUT == SSD1306
  SSD1306AsciiOut outOLED(&oled, tops, pList, 5, 1); //oled output device menu driver
#elif DISPLAY_OUTPUT == SH1106
  // Define geometry and font
  //const uint8_t charW = 6;
  //const uint8_t charH = 10;
  //const uint8_t screenWidthChars = 128 / charW; // ~21
  //const uint8_t screenHeightChars = 64 / charH; // ~6

  // Define the panel (x, y, width, height) in character units
  //rect myPanel(0, 0, 21, 6);
  //const panel myPanel[] MEMMODE = {
  //  {0, 0, 21, 8}
  //};
  //panelsList pList

  // Manual u8g2Out instantiation (7 arguments)
  u8g2Out outOLED(
    oled,    // display object
    colors,  // color palette
    tops,
    pList,
    fontW,   // font width
    fontH,   // font height
    offsetX, // pixel offset X
    offsetY, // pixel offset Y
    1,       // int fontMarginX
    1        // int fontMarginY
  );
#endif

menuOut* constMEM outputs[] MEMMODE  = {&outOLED}; // List of output devices
outputsList out(outputs, 1); // Outputs list

//Macro shortcut. Never tested
//MENU_OUTPUTS(out2,MAX_DEPTH,U8G2_OUT(oled,colors,fontW,fontH,offsetX,offsetY,{0,0,U8_Width/fontW,U8_Height/fontH}));

//Define navroot
NAVROOT(nav, mainMenu, MAX_DEPTH, in, out);





// Create ESP32 timer
// http://www.iotsharing.com/2017/06/how-to-use-interrupt-timer-in-arduino-esp32.html https://techtutorialsx.com/2017/10/07/esp32-arduino-timer-interrupts/
hw_timer_t *timer = NULL;
portMUX_TYPE timerMux = portMUX_INITIALIZER_UNLOCKED;
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
void loop() {
  // Poll the menu for the ArduinoMenu library
  nav.poll();

  // Required for ArduinoOTA
  if (WiFi.status() == WL_CONNECTED) {
    ArduinoOTA.handle();
  }

  //Receive and parse serial data
  serialRecieveLX200();
  if (serialNewData) {
    serialParseData();
  }

  // Move stepper motors if we are homed, a move has been requested and it is safe to do so
  if (hasHomePositionAlt && moveSteppersToTargetStepsAlt) { //We could also check for (stepperAlt.distanceToGo() != 0 || stepperAz.distanceToGo() != 0) but apparently this is handled automatically by accelstepper
    stepperAlt.moveTo(stepperAltTargetSteps);
    if (digitalRead(PIN_ALT_LIMIT_HOME) == HIGH && digitalRead(PIN_ALT_LIMIT_END) == HIGH) {
      stepperAlt.run();
    } else {
      //steppersDisableAndAbortAllCode();
      steppersEnable(false);
      steppersHaltMovement();
    }
  }

  // Move stepper motors if we are homed, a move has been requested and it is safe to do so
  if (hasHomePositionAz && moveSteppersToTargetStepsAz) { //We could also check for (stepperAlt.distanceToGo() != 0 || stepperAz.distanceToGo() != 0) but apparently this is handled automatically by accelstepper
    stepperAz.moveTo(stepperAzTargetSteps);
    if (digitalRead(PIN_AZ_LIMIT_HOME) == HIGH && digitalRead(PIN_AZ_LIMIT_END) == HIGH) {
      stepperAz.run();
    } else {
      //steppersDisableAndAbortAllCode();
      steppersEnable(false);
      steppersHaltMovement();
    }
  }

  //Every updateTrackingRADecInterval milliseconds, check if we are tracking an RA Dec target and if so, recalculate where we should be pointing in Alt Az based on the last given LX200TargetRA and LX200TargetDec
  updateTrackingRADecCurrentMillis = millis();
  if (updateTrackingRADecCurrentMillis - updateTrackingRADecPreviousMillis >= updateTrackingRADecInterval) {
    updateTrackingRADecPreviousMillis = updateTrackingRADecCurrentMillis;
    if (trackingRADecTarget) {
      trackingRADecTarget = positionSetTargetRADec(LX200TargetRA, LX200TargetDec); // If positionSetTargetRADec returns false, stop tracking
    }
  }
}

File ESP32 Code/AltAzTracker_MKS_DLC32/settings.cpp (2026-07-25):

#include "settings.h"

// ##################
// # Const settings #
// ##################
// Defines are fine if the value is only referenced once. Else, it is more efficient to use const. For simplicity for now, using const whenever possible
const int SERIAL_BAUD_RATE   = 9600; //Standard baud rate for LX200 protocol is 9600, 8N1 configuration
const int SERIAL_BUFFER_SIZE = 32;

const int WIFI_SSID_MAX_LENGTH     = 33;
const int WIFI_PASSWORD_MAX_LENGTH = 65;

const char hostname[] = "MKS-DLC32";
const unsigned long WIFI_TIMEOUT_MS = 10000; // 10 seconds

const char defaultPreference_wifiSsid[] = "WiFiSSID";
const char defaultPreference_wifiPassword[] = "WiFiPassword";

const double defaultPreference_latitude  = 51.447;
const double defaultPreference_longitude = 0.0;

const uint8_t serialNumChars                    = 32;
const unsigned long updateTrackingRADecInterval = 1000; //When we are tracking an object via RA Dec coordinates, how often to re-compute position

// Stepper motor settings
//const double ALT_STEPPER_STEPS_PER_REV                        = 144000.0; // For design 1. 200 (steps) * 16 (1/16 microstepping) * 90 (gear teeth) / 2 (2-start worm gear) = 360 degrees (0.0025° per step)
//const double AZ_STEPPER_STEPS_PER_REV                         = 144000.0; // For design 1. 200 (steps) * 16 (1/16 microstepping) * 90 (gear teeth) / 2 (2-start worm gear) = 360 degrees (0.0025° per step)
const double ALT_STEPPER_STEPS_PER_REV                        = 9752.38095238095238; // For design 2.  200 (steps) * 16 (1/16 microstepping) * 64 (big gear teeth) / 21 (small gear teeth) = 360 degrees (0.0025° per step)
const double AZ_STEPPER_STEPS_PER_REV                         = 27105.8823529411764; // For design 2.  200 (steps) * 16 (1/16 microstepping) * 144 (big gear teeth) / 17 (small gear teeth) = 360 degrees (0.0025° per step)
const int WITHIN_STEPS_TO_ARRIVE_AT_TARGET                    = 16;
const float ANGLE_TO_MOVE_OFF_DEPRESSED_LIMIT_SWITCH          = 3.0; // Move 2 degrees away from limit switch if it is depressed while trying to home
const float ANGLE_ALLOWED_WITHIN_LIMIT_SWITCH_BEING_DEPRESSED = 3.0; // Within this angle of the limit switch, ignore if the limit switch is pressed as this is expected
//const bool STEPPER_ALT_MOVE_IN_POSITIVE_DIRECTION             = false; // For design 1
//const bool STEPPER_AZ_MOVE_IN_POSITIVE_DIRECTION              = true; // For design 1
const bool STEPPER_ALT_MOVE_IN_POSITIVE_DIRECTION             = true; // For design 2
const bool STEPPER_AZ_MOVE_IN_POSITIVE_DIRECTION              = false; // For design 2

const float X_STEPPER_MINIMUM_ANGLE              = 0.0; // Home posiiton should always be set at 0. No need to change this
const float X_STEPPER_MAXIMUM_ANGLE              = 360.0;
const float X_STEPPER_ANGLE_OF_NORTH_FROM_HOME   = 0.0;
const float X_STEPPER_ANGLE_OF_SOUTH_FROM_HOME   = 180.0;

const float Z_STEPPER_MINIMUM_ANGLE              = 0.0; // Home posiiton should always be set at 0. No need to change this
//const float Z_STEPPER_MAXIMUM_ANGLE              = 130.0; // For design 1
//const float Z_STEPPER_ANGLE_OF_HORIZON_FROM_HOME = 35.0; // For design 1
//const float Z_STEPPER_ANGLE_OF_ZENITH_FROM_HOME  = 125.0; // For design 1
const float Z_STEPPER_MAXIMUM_ANGLE              = 180.0; // For design 2
const float Z_STEPPER_ANGLE_OF_HORIZON_FROM_HOME = 18.0; // For design 2
const float Z_STEPPER_ANGLE_OF_ZENITH_FROM_HOME  = 108.0; // For design 2

// I2S / 74HC595 stepper shift register
// Bit positions in the 595 output byte (I2SO.x in FluidNC terms)
const int SR_STEPPER_DISABLE_BIT = 0; // I2SO.0  - shared EN (active high disables)
const int SR_X_STEP_BIT          = 1; // I2SO.1
const int SR_X_DIR_BIT           = 2; // I2SO.2
const int SR_Z_STEP_BIT          = 3; // I2SO.3
const int SR_Z_DIR_BIT           = 4; // I2SO.4
const int SR_Y_STEP_BIT          = 5; // I2SO.5
const int SR_Y_DIR_BIT           = 6; // I2SO.6
const int SR_BEEPER_BIT          = 7; // I2SO.7. EXP1 LCD beeper and beeper Maybe EXP1 LCD beeper?

// Shift register
const int PIN_I2S_BCK  = 16; // Clock
const int PIN_I2S_WS   = 17; // Latch. Word select or left/right if I2S
const int PIN_I2S_DATA = 21; // Data

// Endstops (active-low to GND when triggered)
const int PIN_X_LIMIT = 36; // input-only
const int PIN_Y_LIMIT = 35; // input-only
const int PIN_Z_LIMIT = 34; // input-only
const int PIN_Z_PROBE = 22; // Z endstop / probe header. Note - due to wiring on the MKS DLC32 (Component D16 on schematic), never put an input signal on this line greater than 3.3v. Note the header is it found on contains 5v on the vcc pin

// Laser / spindle
//const int PIN_LASER_PWM  = 32; // TTL signal to laser module (0-5V PWM)
//const int LASER_PWM_CH   = 0;
//const int LASER_PWM_FREQ = 5000;
//const int LASER_PWM_RES  = 8;  // 8-bit -> 0..255
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

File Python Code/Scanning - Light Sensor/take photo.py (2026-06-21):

#!/usr/bin/env python3

"""
LX200 Alt-Az Sky Scanner

Scans a rectangular region of the sky using an LX200-compatible Alt-Az mount,
collecting grayscale sensor data at each position and displaying it live.

Features:
- Serpentine raster scanning
- Live matplotlib display
- PNG image saving
- Retry handling
- Slew completion polling
- Ctrl+C safe interruption
- Progress bar + ETA

Dependencies:
    pip install pyserial numpy matplotlib tqdm

Example:
    python3 sky_scan.py \
        --alt1 60 --az1 100 \
        --alt2 30 --az2 160 \
        --rows 10 --cols 10
"""

import argparse
import serial
import time
import numpy as np
import matplotlib.pyplot as plt
from tqdm import tqdm
from datetime import datetime
import sys


# =========================
# Configuration
# =========================

SERIAL_PORT = "/dev/ttyUSB0"
#=#SERIAL_PORT = "/dev/pts/6" #Can be used for MITM testing
BAUD_RATE = 9600

POLL_INTERVAL = 0.2
MOVE_TIMEOUT = 30.0
HOME_TIMEOUT = 30.0
SETTLING_TIME = 0.2
MAX_RETRIES = 3

SERIAL_TIMEOUT = 1.0


# =========================
# Utility Functions
# =========================

def round_to_nearest_minute(degrees_float):
    """
    Round decimal degrees to nearest arcminute.

    Returns:
        (degrees, minutes)
    """
    sign = 1 if degrees_float >= 0 else -1
    abs_deg = abs(degrees_float)

    degrees = int(abs_deg)
    minutes = round((abs_deg - degrees) * 60)

    # Handle rollover
    if minutes == 60:
        degrees += 1
        minutes = 0

    return sign * degrees, minutes


def format_alt_command(alt):
    """
    Format LX200 altitude command:
    :Sa+DD*MM#
    """
    deg, mins = round_to_nearest_minute(alt)

    sign = "+" if deg >= 0 else "-"
    deg_abs = abs(deg)

    return f":Sa{sign}{deg_abs:02d}*{mins:02d}#"


def format_az_command(az):
    """
    Format LX200 azimuth command:
    :SzDDD*MM#
    """
    deg, mins = round_to_nearest_minute(az)

    deg %= 360

    return f":Sz{deg:03d}*{mins:02d}#"


# =========================
# LX200 Communication
# =========================

class LX200Mount:

    def __init__(self, port, baudrate):
        self.ser = serial.Serial(
            port=port,
            baudrate=baudrate,
            timeout=SERIAL_TIMEOUT
        )

    def close(self):
        self.ser.close()

    def send(self, command):
        self.ser.write(command.encode("ascii"))

    def read_until_hash(self):
        return self.ser.read_until(b"#").decode("ascii", errors="ignore")

    def flush(self):
        self.ser.reset_input_buffer()
        self.ser.reset_output_buffer()

    def home_alt_az(self):
        start_time = time.time()

        self.flush()

        self.send(":GA#") # Send ONE GA request

        while True: # Wait until we actually receive data`
            if (time.time() - start_time) > HOME_TIMEOUT:
                raise TimeoutError("Mount home timeout")

            response = self.read_until_hash().strip("#").strip()

            if response == "": # No data received yet
                continue

            break # Got data or serial timeout, stop waiting

        if response != "":
            return # Return if data was received

        self.wait_for_slew_complete()

        self.flush()

        self.send(":GZ#") # Send ONE GZ request

        while True: # Wait until we actually receive a byte
            if (time.time() - start_time) > HOME_TIMEOUT:
                raise TimeoutError("Mount home timeout")

            response = self.read_until_hash().strip("#").strip()

            if response == "": # No data received yet
                continue

            break # Got data or serial timeout, stop waiting

        if response != "":
            return # Return if data was received

        self.wait_for_slew_complete()



    def set_target(self, alt, az):
        alt_cmd = format_alt_command(alt)
        az_cmd = format_az_command(az)

        self.send(alt_cmd)
        time.sleep(0.05)

        self.flush()

        response = self.ser.read(1) #1 if movement is valid. todo

        self.send(az_cmd)
        time.sleep(0.05)

        self.flush()

        response = self.ser.read(1) #1 if movement is valid. todo

    def start_slew(self):
        self.send(":MA#")
        time.sleep(0.05)

        self.flush()

        response = self.ser.read(1) #1 if movement is valid. todo

    def wait_for_slew_complete(self):
        start_time = time.time()

        while True:
            if (time.time() - start_time) > MOVE_TIMEOUT:
                raise TimeoutError("Mount slew timeout")

            self.send(":D#") # Send ONE status request

            while True: # Wait until we actually receive a byte
                if (time.time() - start_time) > MOVE_TIMEOUT:
                    raise TimeoutError("Mount slew timeout")

                response = self.ser.read(1)

                if response == b"": # No byte received yet
                    continue

                break # Got a byte, stop waiting

            if response == b"#": # '#' = still moving
                continue

            if response == b"\x00": # NULL = movement complete
                return

            time.sleep(POLL_INTERVAL) # Ignore unexpected bytes

    def move_to(self, alt, az):
        for attempt in range(MAX_RETRIES):

            try:
                self.flush()

                self.set_target(alt, az)
                self.start_slew()

                self.wait_for_slew_complete()

                time.sleep(SETTLING_TIME)

                return

            except Exception as e:
                print(f"\nMove retry {attempt + 1}/{MAX_RETRIES}: {e}")

                if attempt == MAX_RETRIES - 1:
                    raise

    def read_sensor(self):
        for attempt in range(MAX_RETRIES):

            try:
                self.flush()

                self.send(":Gl#")
                time.sleep(0.05)

                response = self.read_until_hash().strip("#").strip()

                if len(response) != 3:
                    raise ValueError(f"Invalid response length: {response}")

                value = int(response)

                if not (0 <= value <= 255):
                    raise ValueError(f"Value out of range: {value}")

                return value

            except Exception as e:
                print(f"\nSensor retry {attempt + 1}/{MAX_RETRIES}: {e}")

                if attempt == MAX_RETRIES - 1:
                    raise

                time.sleep(0.2)


# =========================
# Scan Coordinate Generator
# =========================
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

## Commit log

2026-06-14 Upload OpenSCAD model
    [AltAzMount OpenSCAD Gears.scad, Main_WormGearDesign Nema 17_spur.stl, Main_WormGearDesign Nema 17_spur_worm_keyed.stl]
2026-06-14 Upload SketchUp model
    [AltAzTrackerSketchup.skp, AltAzTrackerSketchup_18650 Sideways Battery Holder.stl, AltAzTrackerSketchup_Base Vertical Shaft 1.stl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]
2026-06-14 Upload ESP32 code
2026-06-15 Move LED_PIN from arduino_menu.h to settings.h and .cpp
2026-06-19 Fixed lat and long typo
    [AltAzTracker_MKS_DLC32.ino]
2026-06-19 ESP32Time's getHour() must be (true) for 24h time
2026-06-20 Improve rotary encoder response. Moved from menuIO/encoderIn.h to ClickEncoder.h and menuIO/ClickEncoderIn.h
2026-06-20 Update light sensor scanning command
2026-06-20 Stop idle menu disabling stepper motors
2026-06-20 Fixed typo in LX200 :MA# command
    [functions_LX200.cpp]
2026-07-19 Added connecting to wifi and flashing over ArduinoOTA. Wifi settings can be saved and loaded with preferences.h
2026-07-19 Added variables to settings.cpp to make it easier to reassign stepper motor and limit switch pins
2026-07-22 Fixed AccelStepper to not mess with pins that share their number with the bit number on the shift register. Added fallback string null termination for wifi creds
    [custom_AccelStepper_overwrites.cpp, settings.cpp]
2026-07-25 Updated AltAzTrackerSketchup.skp and exports
    [AltAzTrackerSketchup.skp, AltAzTrackerSketchup_Y Camera Mount Top Tripod Pin.stl]
2026-07-25 Uploaded new design removed from isaac879's pan tilt mount. Old design moved to a new folder
    [127_x_146.05_x_12.7mm_Printable_Bearing_Cage_Part_3.stl, 127_x_146.05_x_12.7mm_Printable_Bearing_Part_1.stl, 127_x_146.05_x_12.7mm_Printable_Bearing_Part_2.stl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]
2026-07-25 Modified code for Design 2. Steps per revolution setting now per axis. Added custom menu entry for pointing at Sun. Reordered menus. Added fallback datetime if RTC missing
    [AltAzTracker_MKS_DLC32.ino, functions_movement.cpp, settings.cpp]
2026-07-25 Updated README.md
    Updated the README to include details about two 3D print designs, including a deprecated original design and a remix of isaac879's design with a list of changes.
2026-07-25 Update README.md
    Added sections for SketchUp and OpenSCAD 3D prints.
2026-07-26 Updated design 2. New STL exports
    [Remix of isaac879 Pan Tilt Camera Mount_40mm Fan Guard.stl, Remix of isaac879 Pan Tilt Camera Mount_40mm Fan Mount.stl, Remix of isaac879 Pan Tilt Camera Mount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]
2026-07-26 3D Print Design 2 - Removed duplicate file
    [Remix of isaac879 Pan Tilt Camera Mount_Fan Mount.stl]
2026-07-29 Added video to 3D Print Design 2 README.md
2026-08-02 Updated Design 2. Updated fan mounts. Added stepper motor covers, sun shield, ground spike and modified 21 tooth gear for tighter tolerances
    [Remix of isaac879 Pan Tilt Camera Mount_40mm Fan Mount.stl, Remix of isaac879 Pan Tilt Camera Mount_Camera Mount Top Tripod Pin.stl, Remix of isaac879 Pan Tilt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]
